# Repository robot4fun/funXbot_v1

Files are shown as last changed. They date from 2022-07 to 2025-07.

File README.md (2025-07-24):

<p align="center">
  <picture>
    <source media="(prefers-color-scheme: dark)" srcset="doc/funxedu-logo4-white.png">
    <source media="(prefers-color-scheme: light)" srcset="doc/funxedu-logo4-black.png">
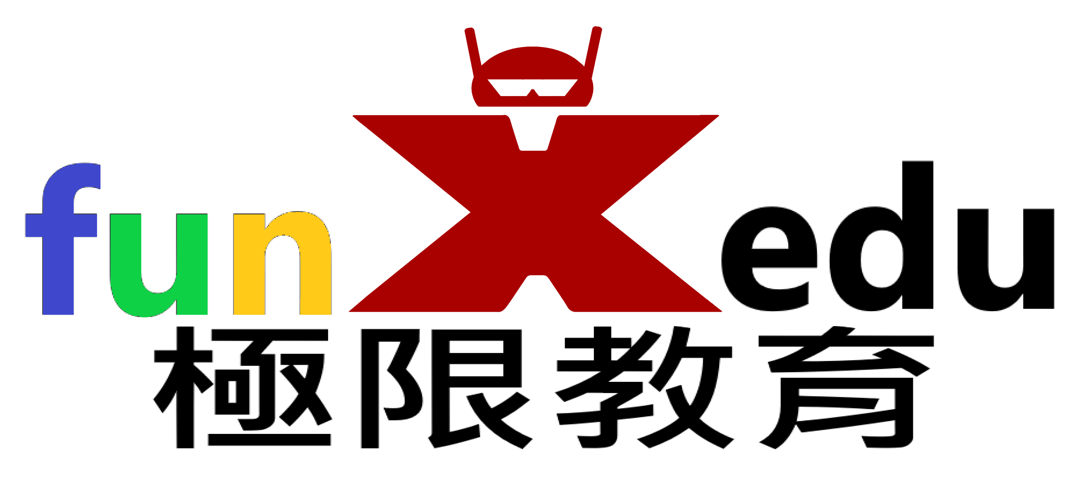
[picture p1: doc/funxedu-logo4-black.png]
funXedu
    
  </picture>
  <br/>
</p>

`funXbot v1` 是一個低成本、DIY（自己動手做）的機器人套件項目，專為教育用途設計。

!! 此專案授權僅限個人或學校教學非商業用途。嚴禁任何商業使用、分發或用於商業目的之修改 !!

# 項目包含三大部分
* `funXbot`: 主機、電池盒、感應器、顯示設備和馬達等設備，搭配樂高規格相容積木所組成的完整教育機器人套件
* `funXtcp`: 使用 `KittenBot` (基於 `esp-link` 技術) 韌體的 WiFi 模組，讓 `funXbot v1` 具備無線功能
* `funXblock`: 基於 `Kittenblock` 積木編程軟體 (基於 `Scratch`，但增加了上傳程式讓機器人離線自主動作的功能)，是 `funXbot v1` 的程式開發環境(IDE)，目前僅有 Windows 版

# funXbot v1 套件可以怎麼玩?
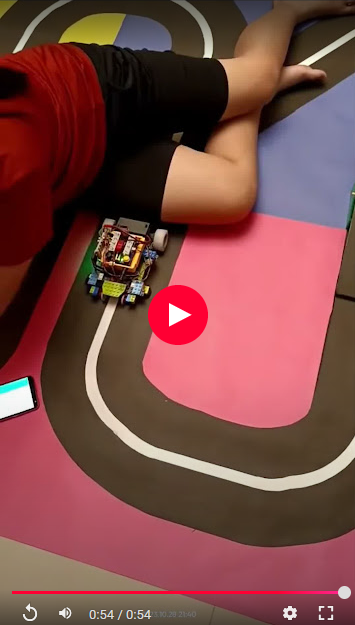
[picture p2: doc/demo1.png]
(https://photos.app.goo.gl/XpYc3omgsmDtc2Y2A)

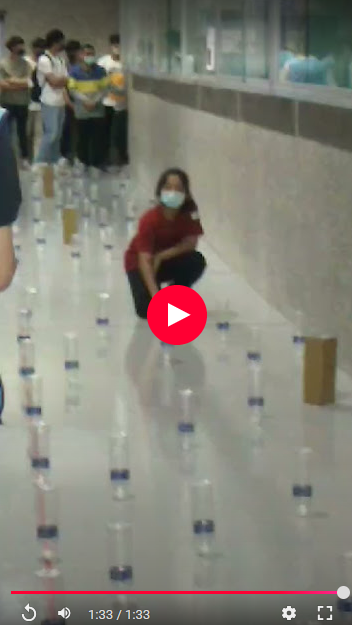
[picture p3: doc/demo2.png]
(https://photos.app.goo.gl/KkY9mZn8f1qZUgqs6)


# DIY 材料清單
* 主機:
    * 32-pin TQFP 封裝的 Arduino UNO R3 開發板
    * MPU6050 加速度計和陀螺儀模組 (I2C接口)
    * 凱斯電子 KSB030 S4A 擴充板
    * Arduino UNO 樂高積木外殼 或 一般外殼

* 電池盒: 可裝2顆14500鋰電池串聯(8.4V)，需附開關，插頭為圓頭 DC 5.5x2.1mm

* funXtcp WiFi模組:
  * ESP12S 模組
  * 洞洞板 + 排針
  * 10KΩ 以上 + 2倍阻值 電阻

* 感應器:
    * 數位感應器模組，例如：紅外線避障、按鈕等
    * 類比感應器模組，例如：紅外線測距
    * HC-SR04 超聲波距離感應器模組
    * DHT11 溫濕度感應器模組
    * TCS34725 RGB顏色感應器模組 (I2C接口)
    * PCF8574T IO擴展模組 (I2C接口)
    * CD74HC4067 類比IO擴展模組
    * QTR-8A 循線模組
    * QMC5883L 磁力計 (I2C接口)
    * 碼盤計數模組

* 顯示設備:
  * TM1637 數字顯示模組
  * MAX7219 8x8 LED顯示模組
  * WS2812B 5050 RGB LED燈條或燈環

* 馬達:
  * SG90 或 MG90 伺服馬達
  * SG90 或 MG90 360度連續旋轉馬達(當一般馬達用)
  * MX1508 直流馬達驅動板
  * USB MicroB 或 TypeC 公 及 母 PCB板
  * TT 直流有刷馬達 或 樂高馬達

* 線材:  
  * 匹配UNO開發板 USB 接口型式的 USB `數據線`
  * RJ11 `6P4C` 和 `6P6C` 水晶頭
  * 電話 或 網路線 (剝皮取線)
  * 杜邦線
  * 熱縮套管

* 樂高規格積木

## 所需工具
* `3D列印機`: 用於製作樂高相容外殼
* `焊接工具`: 用於電路接線
* `RJ11壓接鉗`: 用於連接水晶頭和線材
* `熱風槍`: 熱縮套管用
* `燒錄器`: 用於燒錄程式到 ESP12S 模組中
* `熱熔膠槍`: 用於固定電路板和絕緣
* `PVC膠水`: 用於黏接積木和外殼
* `Windows電腦`: 用於安裝 `funXblock`
* `14500鋰電池充電器`

# funXbot v1 製作方法
## `主機`
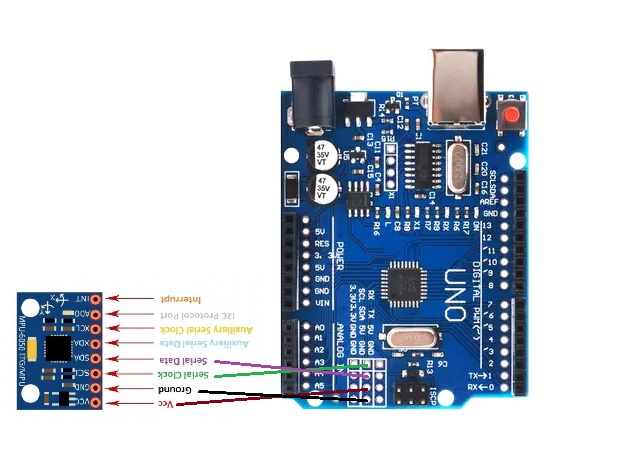
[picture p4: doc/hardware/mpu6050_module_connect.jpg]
  1. 依圖連接 MPU6050 模組和 UNO 開發板後，將 MPU6050 模組依圖示方向 ( x軸朝向左, y軸朝向後, z軸朝上 ) 固定於開發板上 

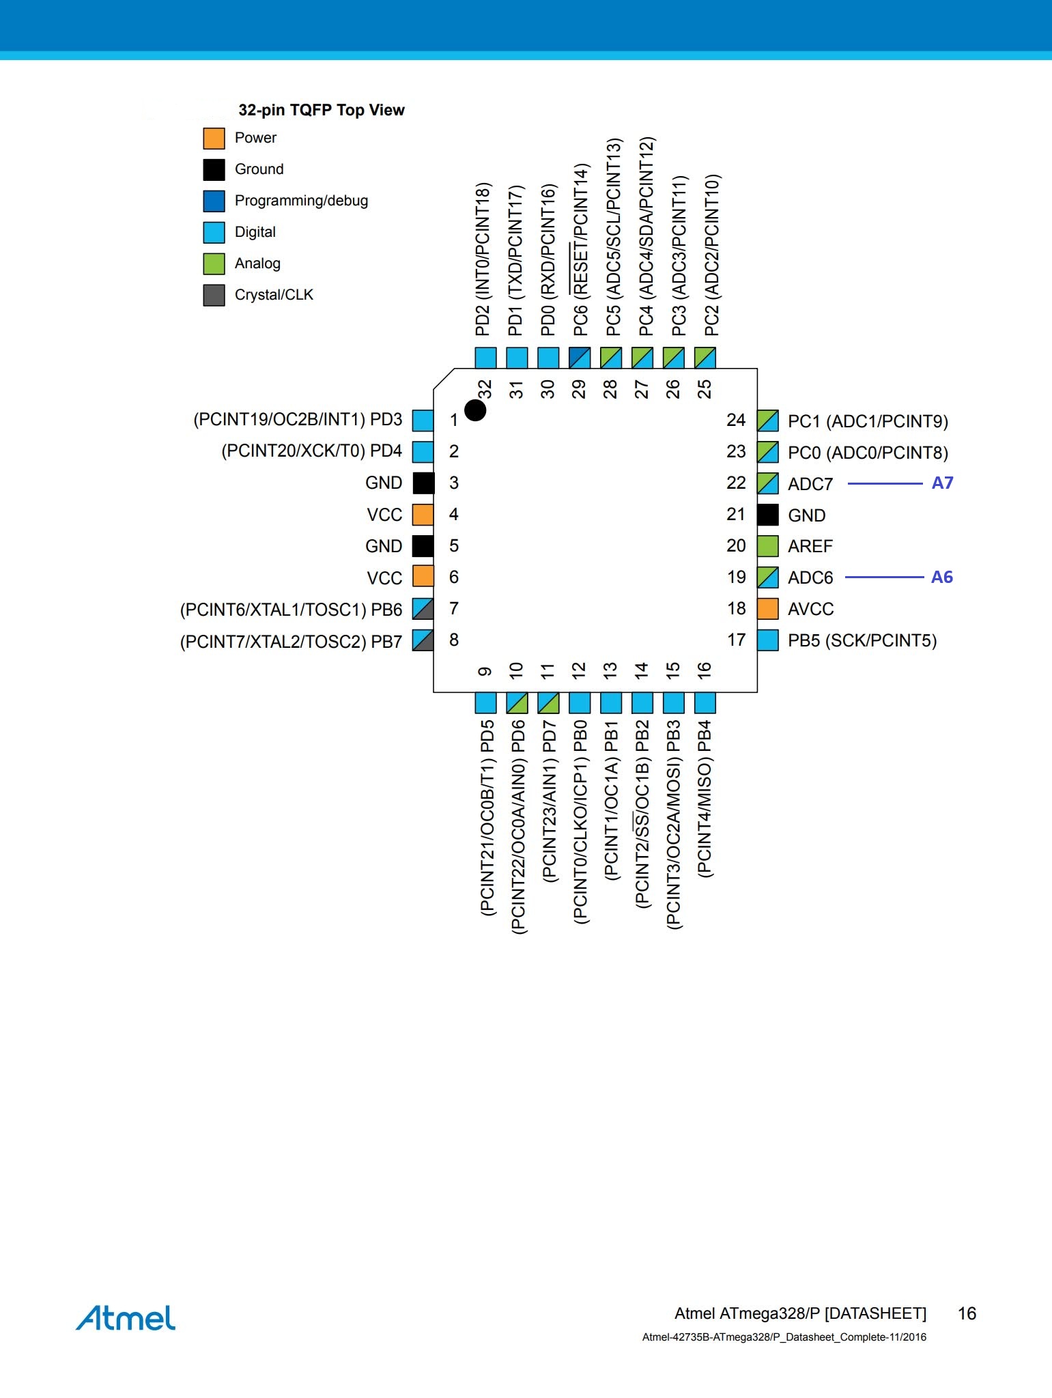
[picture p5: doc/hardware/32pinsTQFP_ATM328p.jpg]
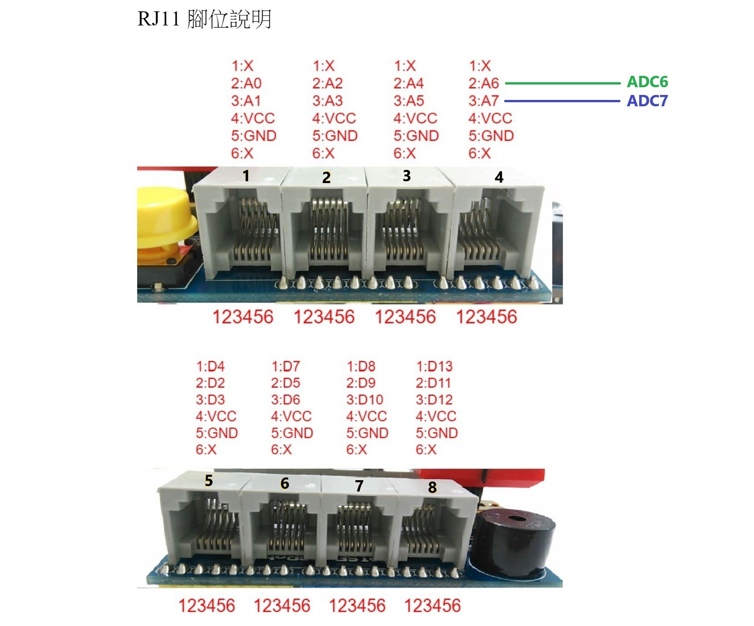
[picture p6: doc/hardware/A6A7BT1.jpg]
  2. 將32-pin TQFP封裝的 ATmega328/P ADC6, ADC7 接到 擴充板的RJ11 A6, A7  

  3. 依照片將擴充板的RJ11接口寫上編號，方便之後連接線材
  
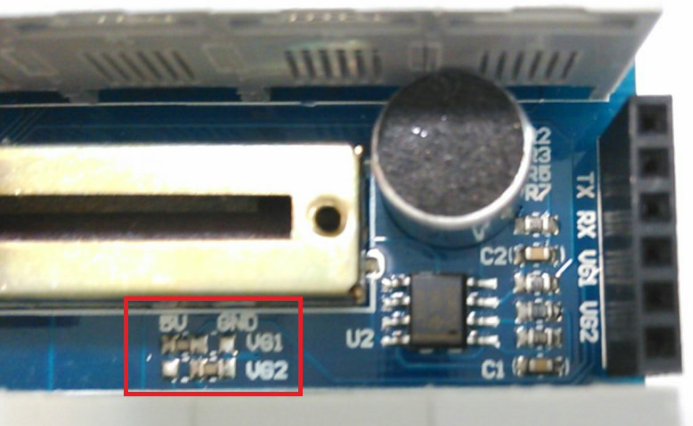
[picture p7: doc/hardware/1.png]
  4. 將擴充板的無線通訊接口(BT1) VG1相對應的電阻移除 

  5. 將擴充板的無線通訊接口(BT1)的VG1腳位接3.3V (funXtcp WiFi模組用)

  6. 將無線通訊接口(BT1) pin6(VG2旁空腳位) 做記號後接 UNO板 RESET 腳位

  7. 將擴充板插入UNO插座後放入Arduino UNO 樂高積木外殼 或 一般外殼中

  8. 如果採用一般外殼，需要在外殼周圍和底部用PVC膠黏接積木，確保積木不會掉落

## `電池盒`
底部用PVC膠黏接積木，確保積木不會掉落

## `funXtcp` WiFi模組
  * 下載 [`wifi/`](/wifi) 目錄內所有韌體檔案 ( *.bin ) 到電腦

  * 將ESP12S模組正確放在 `燒錄器` 上 (如果使用 `USB to TTL` 或 `開發板` 當燒錄器，請確保接線和電壓正確)
  
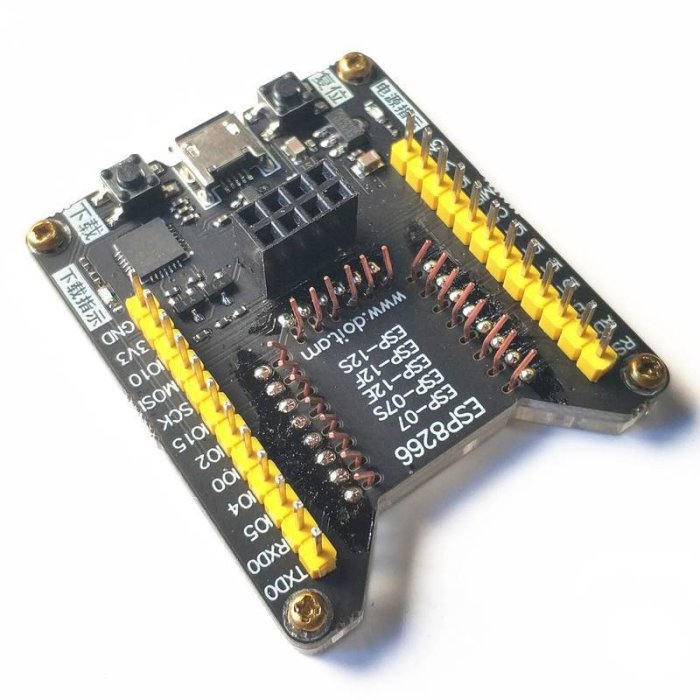
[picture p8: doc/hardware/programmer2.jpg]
  
  
  * 以 `USB 訊號線` (不是充電線) 連接 `電腦` 和 `燒錄器` 

  * 點選進入 [`燒錄工具網頁版`](https://espressif.github.io/esptool-js/)

  * 點選網頁 `Connect` 按鈕，選擇正確的`USB端口` 後點選 `連線`
  
  * `Flash Address` 設為 `0x0` ，點選 `選擇檔案` 按鈕後選擇之前下載的韌體檔 [boot_v1.7.bin](wifi/boot_v1.7.bin)

  * 點選 `Add File` 按鈕後會增加一列，依下表依序增加韌體檔

    | Flash Address | File |
    | :-----------: | :-----: |
    | 0x0000 | [boot_v1.7.bin](wifi/boot_v1.7.bin) |
    | 0x1000 | [user1.bin](wifi/user1.bin) |
    | 0x3FC000 | [esp_init_data_default_v08.bin](wifi/esp_init_data_default_v08.bin) |
    | 0x3FE000 | [blank.bin](wifi/blank.bin) |
  
  * 點選網頁 `Program` 按鈕後開始燒錄韌體
  * 燒錄完成後點選網頁 `Disconnect` 按鈕

  * 按壓ㄧ下燒錄器的 `復位` 按鈕，讓ESP12S模組重新啟動
  
  * 筆電WiFi連接 ESP12S模組 ( 預設SSID: `ESP_00xx` ) 後
    * 以瀏覽器連192.168.4.1 
    * 進入網頁後選 `Upgrade Firmware` 頁面 
    * 點選 `選擇檔案` 選取 [user2.bin](wifi/user2.bin)之後點選 `Update the firmware`
    * reload網頁後將 `serial LED` 改為 `GPIO2` 
    * 視情況更改 `Reset` 腳位，應該是 `GPIO13` 
    * 更新韌體回 [user1.bin](wifi/user1.bin) 
    * 點選 `Home` 頁面後更改 `Hostname` 為 `funXbot`
    * 點選 `WiFi Soft-AP` 頁面後更改 `SSID` 為 `funXtcp00xx` (以MAC當序號)
    * 更改 `Password` 為 `12345678`

  * 拔除 `USB 數據線` 後取下 `ESP12S模組`
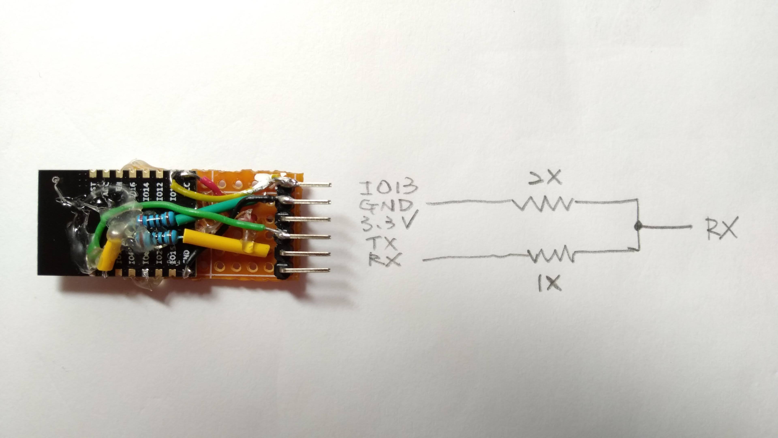
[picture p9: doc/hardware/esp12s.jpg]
  * 依圖自行焊接  之後在 `IO13` 針腳做標記 
  * 用熱縮套管包覆焊接處，確保不會短路

## `其他設備`
* RJ11 `6P4C` 水晶頭會連接母座的 `2-5腳位`，RJ11 `6P6C` 水晶頭會連接母座的 `1-6腳位` 
* 除電源和接地外，請按以下說明接線:
* 1個水晶頭分支接多設備情況下，`腳位1` 設備標記 `C`，`腳位2` 設備標記 `B`，`腳位3` 設備標記 `A`

* `感應器`: 
  * 類比、數位、DHT11溫溼度 等感應器訊號接 `腳位3` 
  * 超音波感應器 `trig` 訊號接 `腳位2`， `echo` 訊號接 `腳位3`
  * I2C類感應器 `SDA` 訊號接 `腳位2`， `SCL` 訊號接 `腳位3`

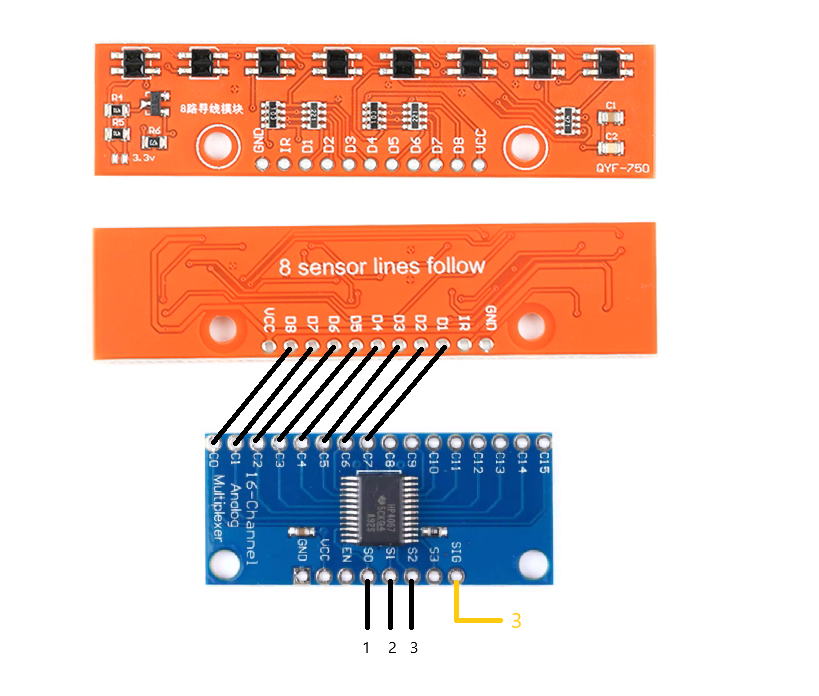
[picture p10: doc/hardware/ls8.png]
* `8路循線感應器`: 由 `QTR-8A 循線模組` 和 `CD74HC4067 類比IO擴展模組` 組成  將兩者的對應腳位連接後，使用 `6P6C` 水晶頭將 CD74HC4067 類比IO擴展模組的 `s0` 接 `腳位1`， `s1` 接 `腳位2`， `s2` 接 `腳位3`， `SIG` 需額外的 `6P4C` 水晶頭，接 `腳位3` 。

* `16路循線感應器`:
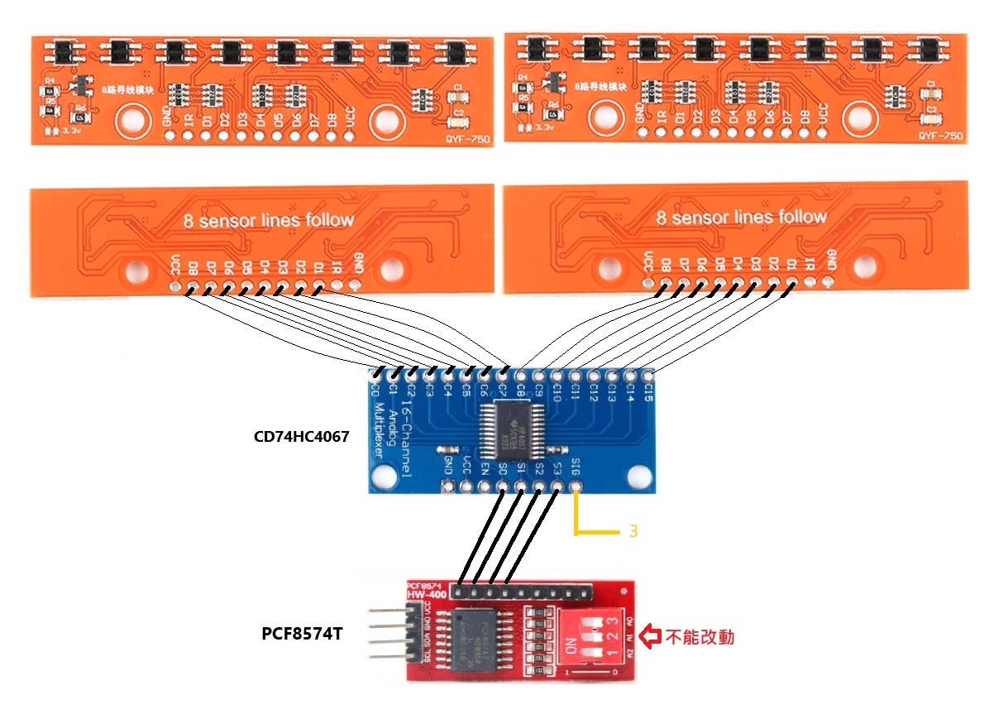
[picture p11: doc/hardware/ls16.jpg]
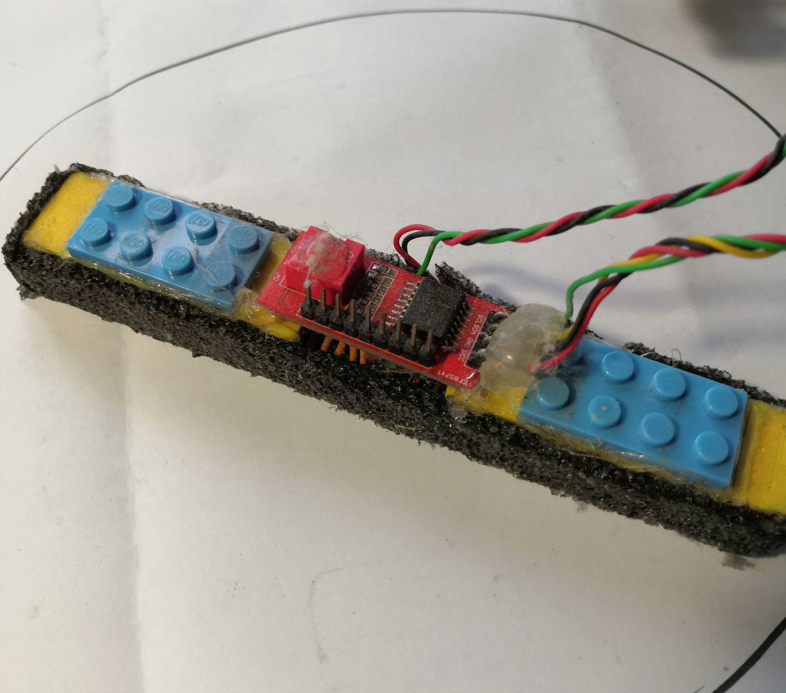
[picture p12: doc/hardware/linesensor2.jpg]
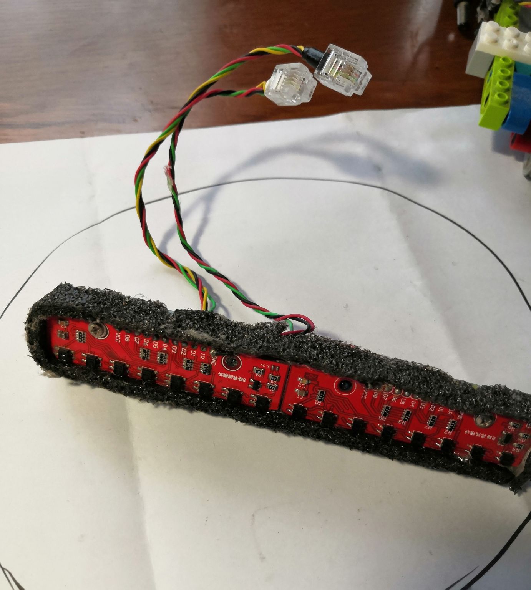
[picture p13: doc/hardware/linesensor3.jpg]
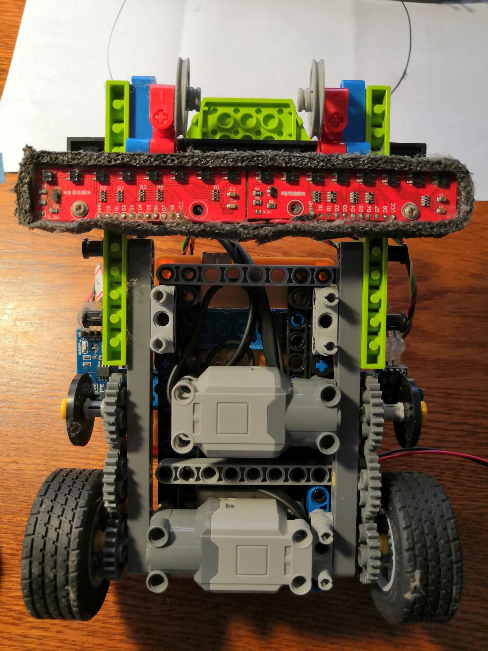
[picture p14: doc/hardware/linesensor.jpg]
  * 2張 `QTR-8A 循線模組` 、 `CD74HC4067 類比IO擴展模組` 和 `PCF8574T IO擴展模組` 組成  依圖將三者的對應腳位連接後，使用 `6P4C` 水晶頭將 PCF8574T 的  `SDA` 訊號接 `腳位2`， `SCL` 訊號接 `腳位3`， CD74HC4067 的 `SIG` 需額外的 `6P4C` 水晶頭，接 `腳位3` 。
  * 如果同時要使用 `顏色感應器` ， 須製作 I2C 轉接頭

* `顯示設備`:
  * TM1637數字顯示板的 `clk` 接 `腳位2` ， `dio` 接 `腳位3`
  * 燈條或燈環訊號接 `腳位3`
  * 將兩個 MAX7219 LED 顯示板拼接後，使用 `6P6C` 水晶頭， `clk` 接 `腳位1` ， `cs` 接 `腳位2` ， `din` 接 `腳位3`

* `馬達`:
  * 伺服馬達接 `腳位3`
  * 360連續旋轉伺服馬達接 `腳位2`  
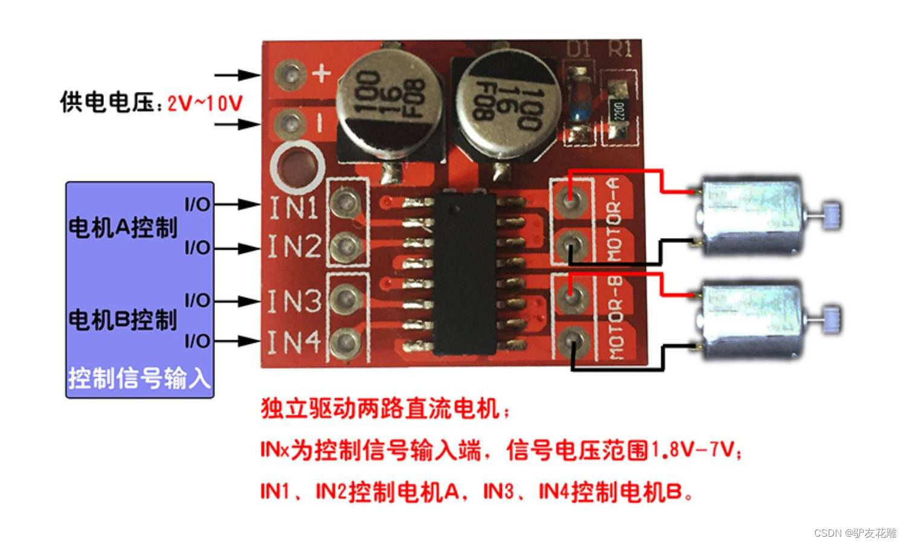
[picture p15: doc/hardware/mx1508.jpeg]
  * 直流馬達需接入 `MX1508 直流馬達驅動板`  1張可驅動2台馬達，因為便宜，每張驅動1台馬達就好。將其黏接在TT馬達上，依圖說接線， `IN1` 接 `腳位2` ， `IN2` 接 `腳位3` 
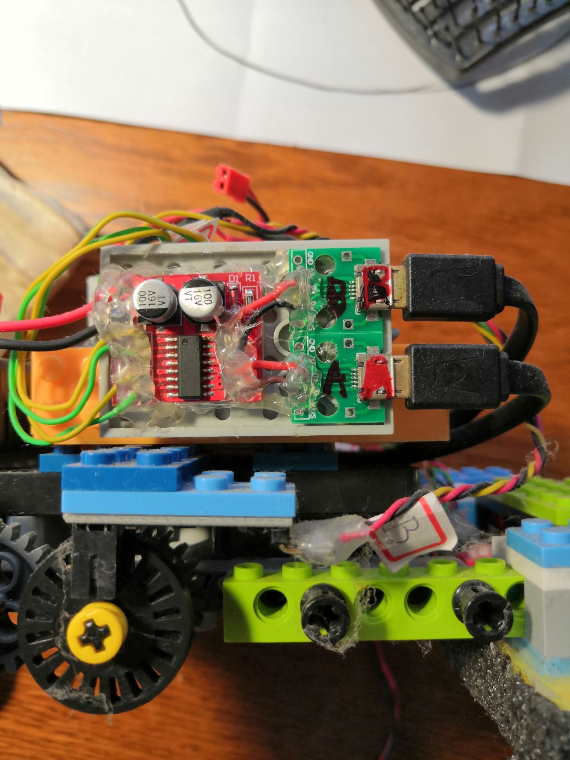
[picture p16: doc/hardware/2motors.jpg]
  * 如果要同時驅動2台直流馬達，須將MX1508驅動板的 `MOTOR` 接 USB `MicroB` 或 `TypeC` 母座，馬達接USB公頭，較為方便
  * 如果要增加馬達功率，可將MX1508驅動板的電源接電池側(可增加電池保護板)，但驅動電流最大也僅2A

* 設備接好線後，可用熱熔膠黏接積木當底座，或3D打印製作外殼( [ `3d/`](3d/) 目錄內有一些設計 )

# `funXblock` 安裝方法
1. 點選下載 [Kittenblock 1.8.4](https://github.com/robot4fun/funXbot_v1/releases/download/v1.0.0/Kittenblock.Setup.1.8.4.exe) 後安裝

2. 點選下載 [`funXblock`](https://github.com/robot4fun/funXbot_v1/archive/refs/tags/v1.0.0.zip) 後解壓縮(或依下圖方式下載)
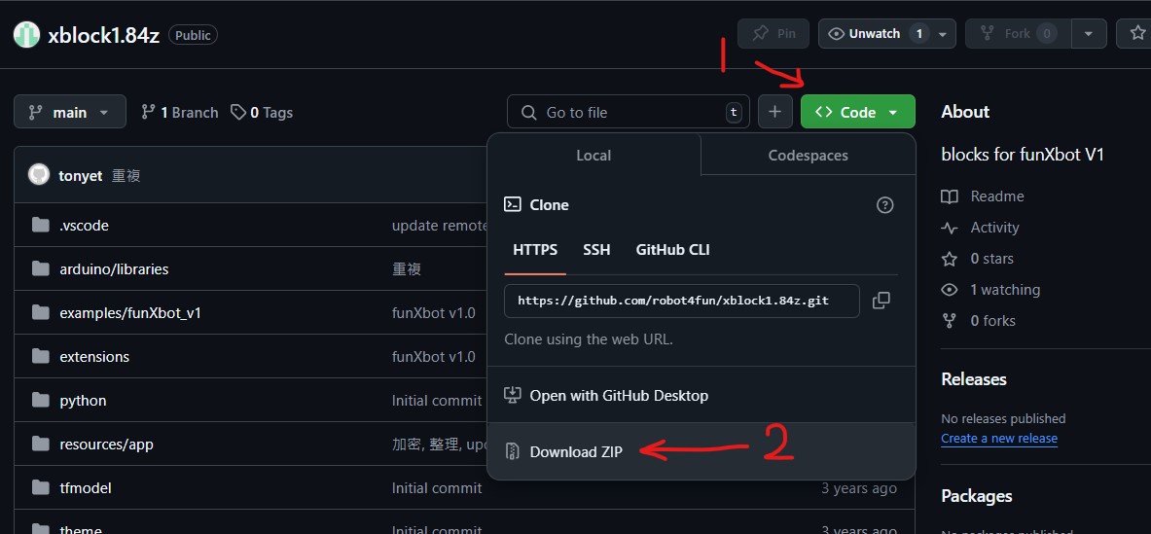
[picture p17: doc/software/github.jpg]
   

4. 以 "管理員權限" 執行 `install.bat`

## 如何在 funXblock 中使用 funXbot v1
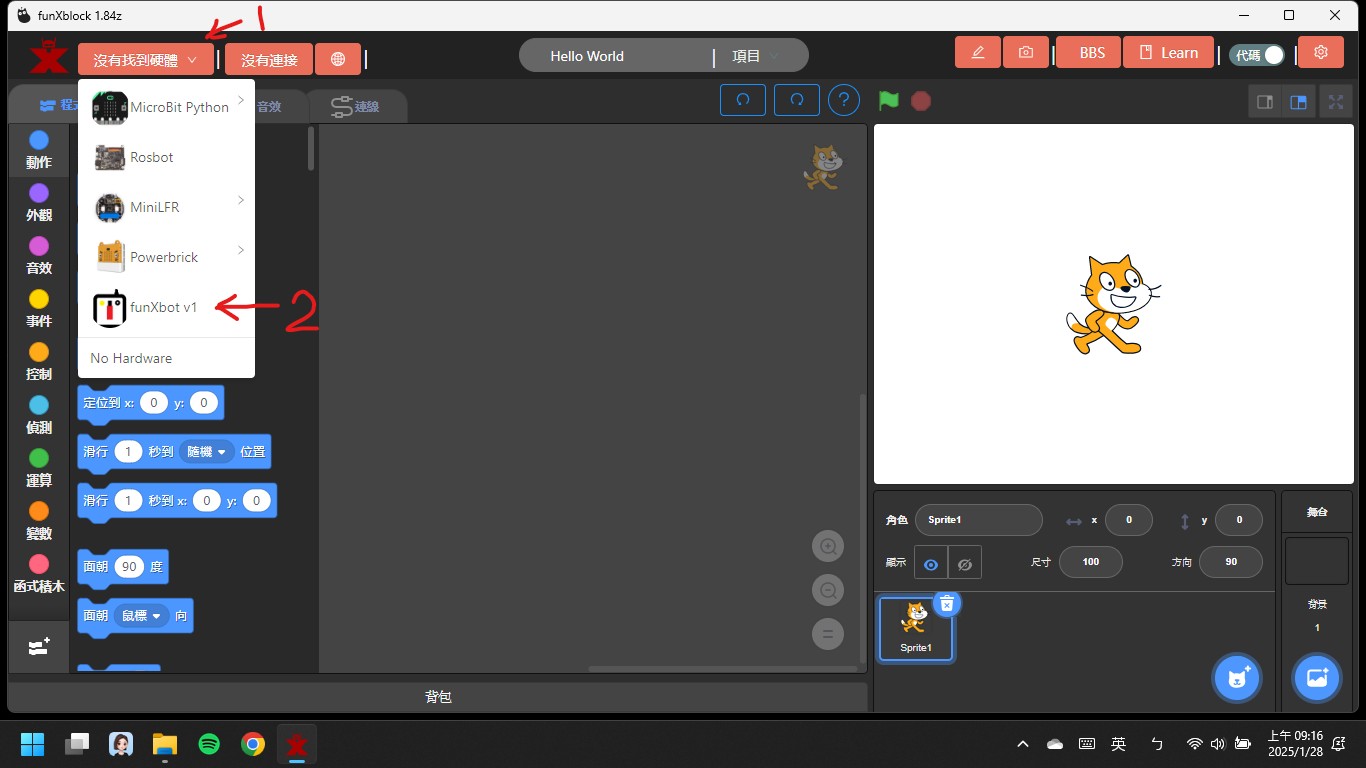
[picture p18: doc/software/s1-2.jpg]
1. 在硬體選單中點選 `funXbot v1`

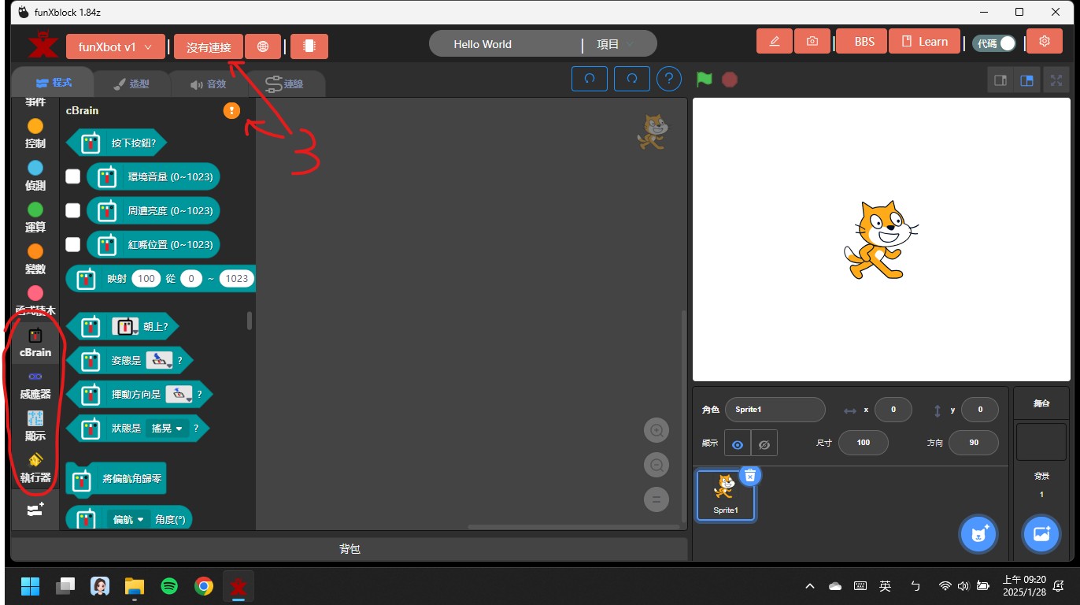
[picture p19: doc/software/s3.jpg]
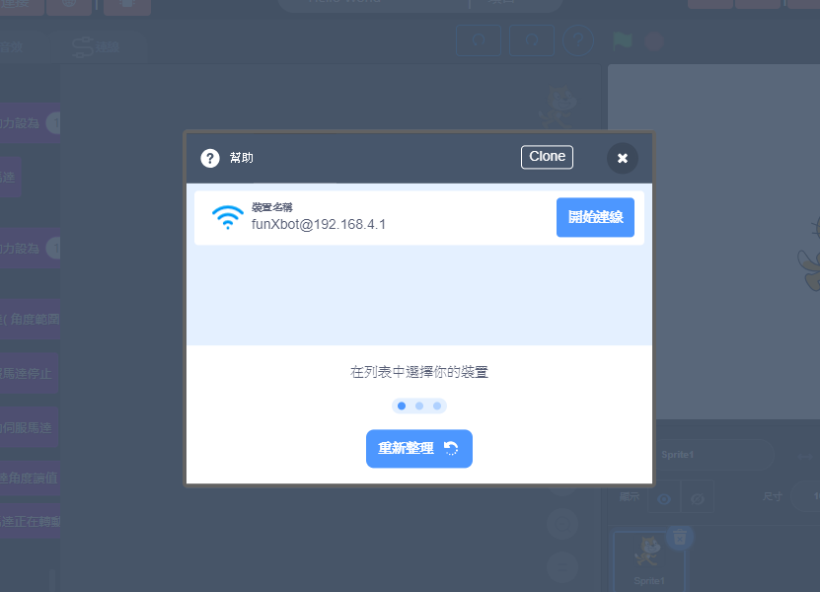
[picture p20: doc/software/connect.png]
2. 點選 `沒有連接` 按鈕或圖示後選擇正確的WiFi或USB埠 `開始連線` funXbot

3. 預設為 `舞台模式` (on-line), 可和電腦連線互動. 如果無法互動, 請點選 `升級韌體`

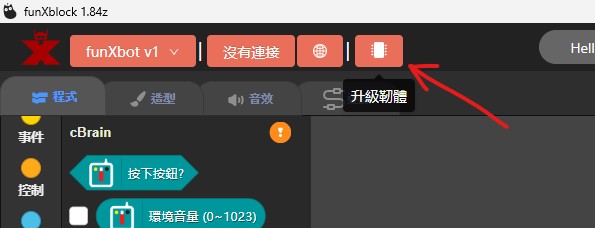
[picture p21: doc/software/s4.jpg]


4. 如果要讓 funXbot 獨立運作, 請點選 `編程模式` (off-line)

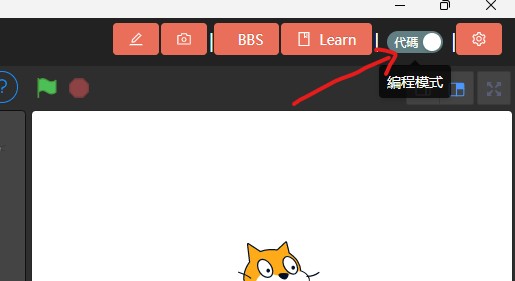
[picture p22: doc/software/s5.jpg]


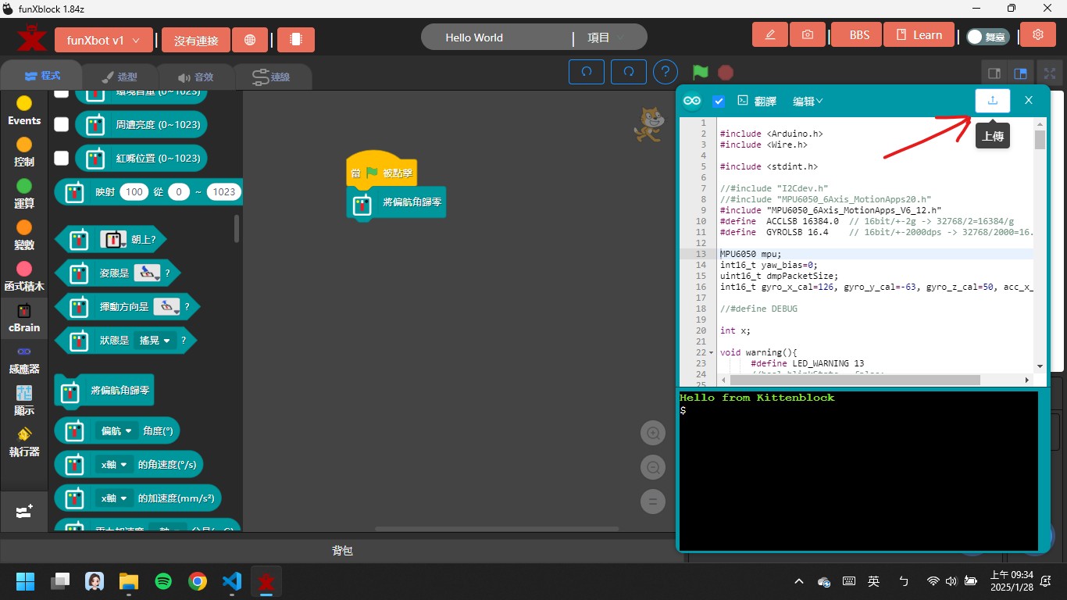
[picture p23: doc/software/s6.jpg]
5. 點選 `編程模式` 後, 會出現C++ 編程視窗, 這裡會自動翻譯積木語言為C++語言. 程式完成後點選 `上傳` 即可上傳到 funXbot 中 

6. 點選 `舞台模式` 即可回到舞台

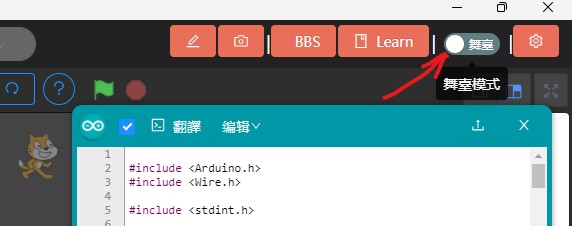
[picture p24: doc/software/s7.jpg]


7. 一旦 `編程模式` (off-line)下曾經上傳過程式, 要再回到 `舞台模式` 和電腦連線互動, 就必須再點選 `升級韌體` 後才可以

# funXbot v1 使用注意事項
1. 接口1A不能和主機內建 光強度感應器 同時使用

2. 接口1B不能和主機內建 滑動式可變電阻(紅嘴) 同時使用

3. 接口2B不能和主機內建 聲強度感應器 同時使用

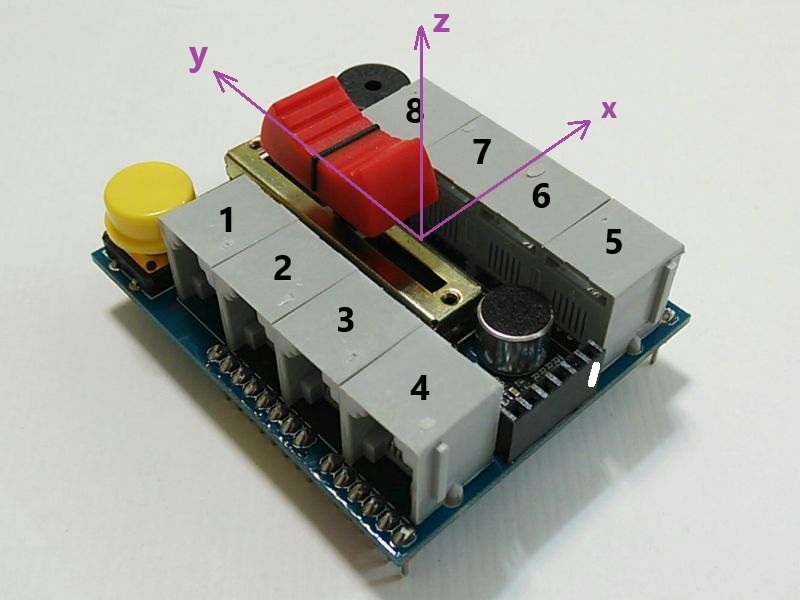
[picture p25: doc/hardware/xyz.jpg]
4. funXblock程式積木所指x軸為朝接口5-8方向; y軸朝向USB及電源接口方向

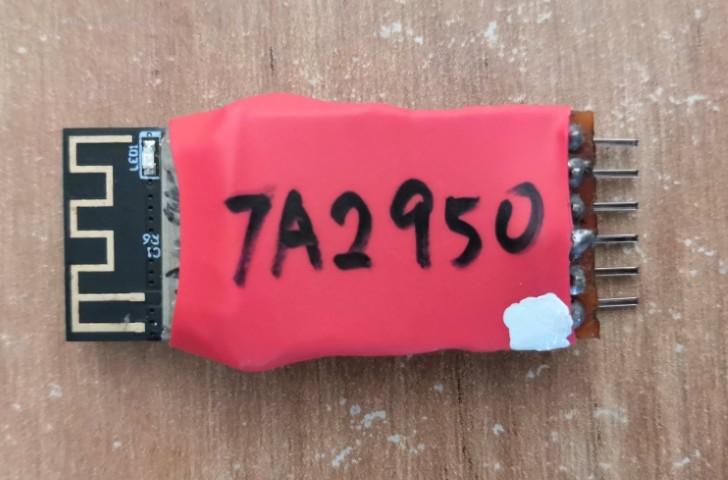
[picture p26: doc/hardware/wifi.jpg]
5. 安插 funXtcp WiFi 模組時, 白色標記需和主控器無線通訊接口白色標記對齊

6. 無線通訊接口無法和有線通訊接口(USB) 同時使用. 使用USB前, 請先拔除funXtcp WiFi 模組

7. 使用無線通訊前, 需先在Windows 連無線網路(SSID: funXtcp00xx, 預設密碼12345678), 再在funXblock中連 funXbot

8. 可使用USB或電池盒供電. 電池盒需要2顆 14500 鋰電池串聯(8.4V), 請勿使用電壓不足的電池, 例如鹼性或鎳氫電池

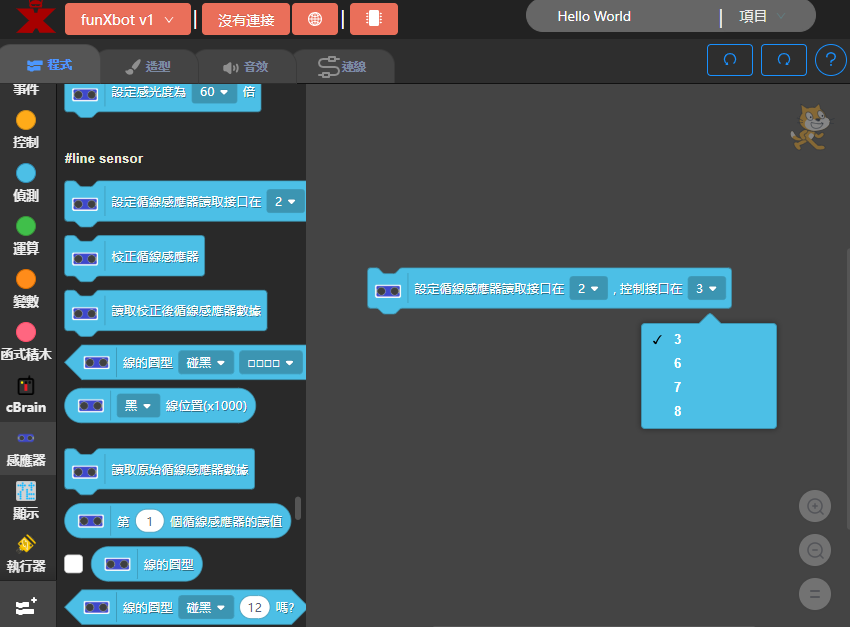
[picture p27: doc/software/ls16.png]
9. `16路循線感應器` `控制接口` 需選 `3`

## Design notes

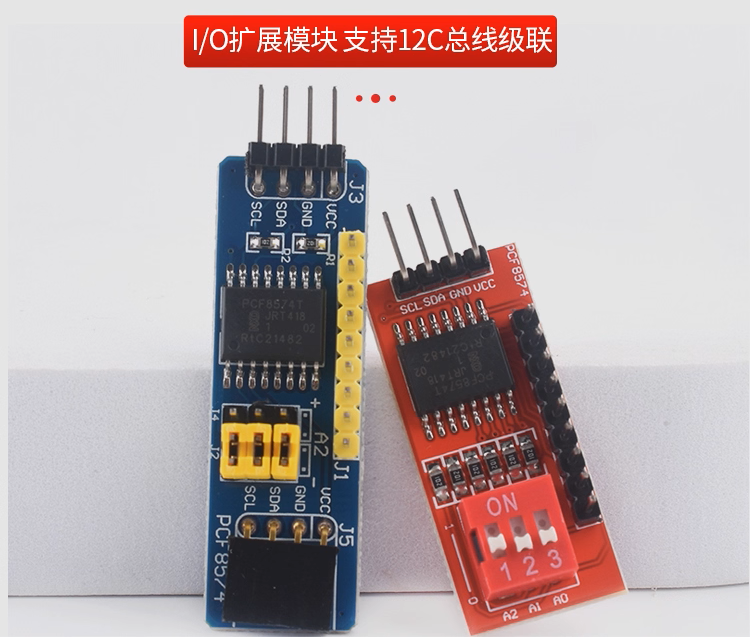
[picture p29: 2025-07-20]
doc/hardware/pcf8574.png

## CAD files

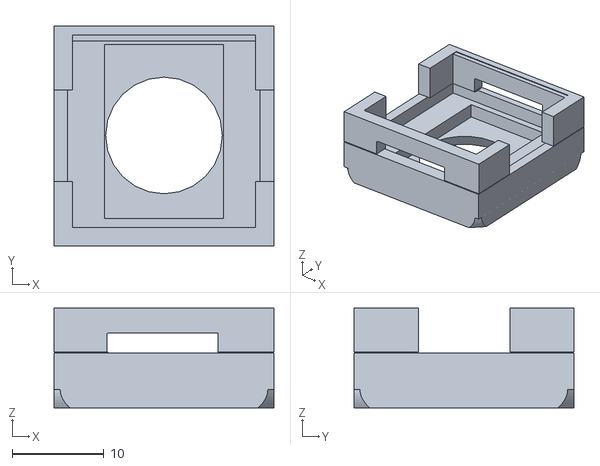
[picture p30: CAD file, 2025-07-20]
3d/color sensor hat v3.stl
24.0 x 24.0 x 10.9

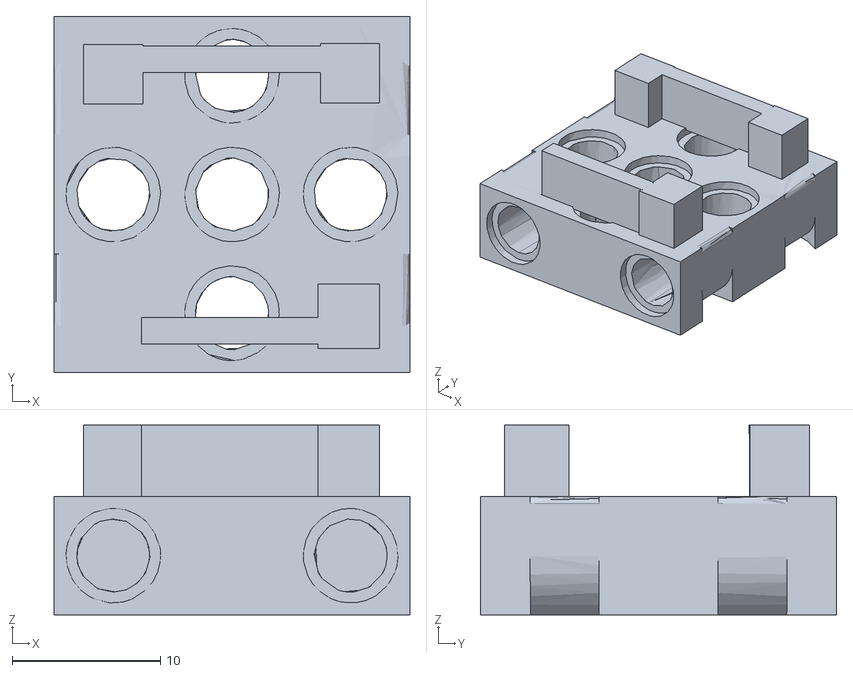
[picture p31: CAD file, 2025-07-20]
3d/color sensor base v4.stl
24.0 x 24.0 x 12.8

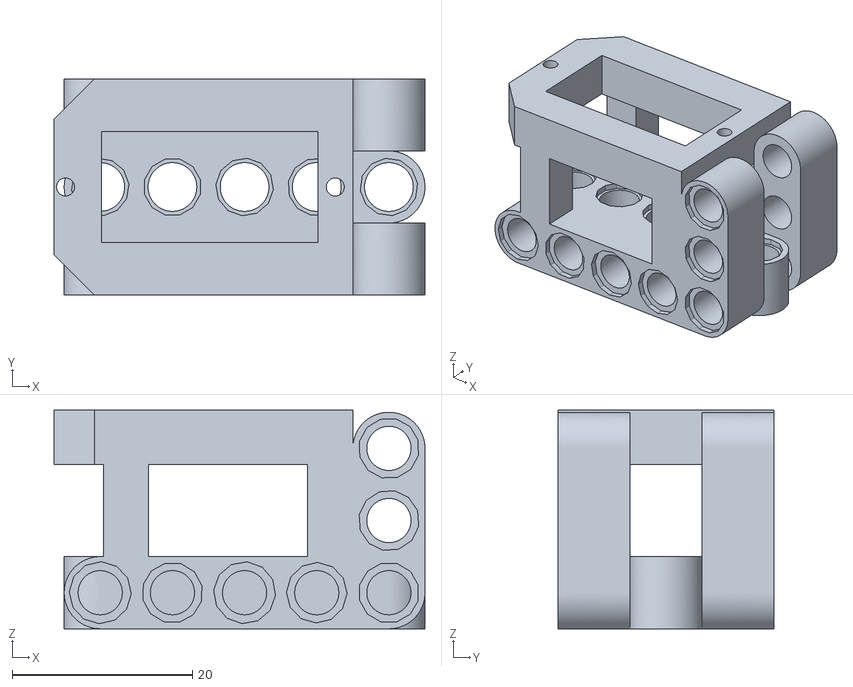
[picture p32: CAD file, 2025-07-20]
3d/servo.stl
41.1 x 24.0 x 24.2

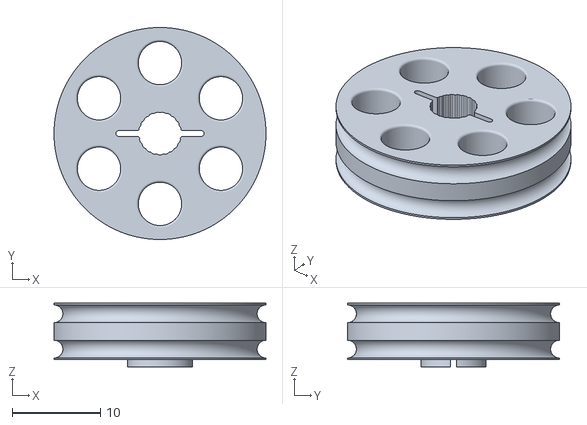
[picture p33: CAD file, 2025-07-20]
3d/9g_servo_fitting_doublepully.STL
24.0 x 24.0 x 7.20

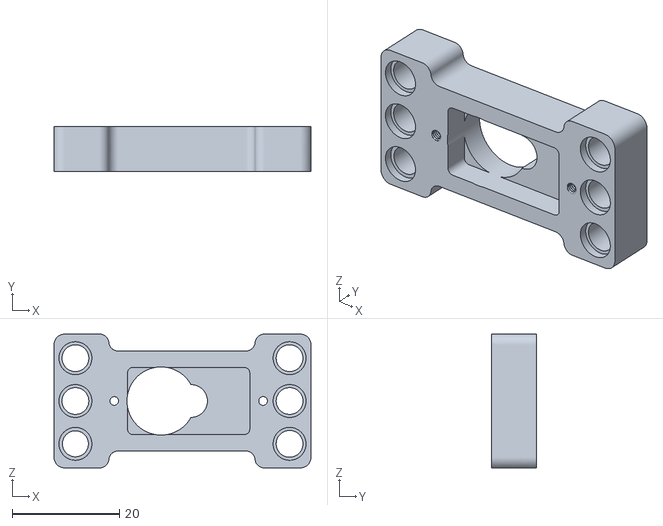
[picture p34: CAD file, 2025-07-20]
3d/SG90_-_Micro_Servo_9g_-_Tower_Pro_v2_LEGO.stl
48.0 x 8.45 x 25.0

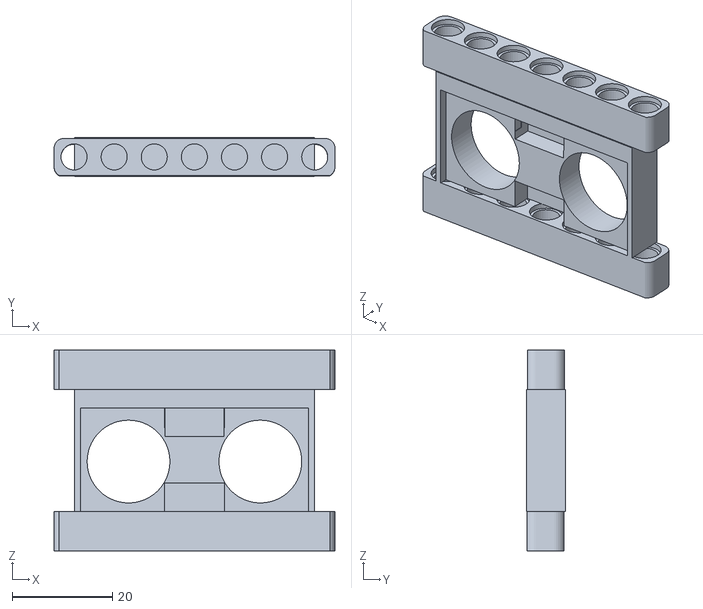
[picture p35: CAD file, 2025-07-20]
3d/HC-SR04 v2.stl
56.0 x 7.80 x 40.1

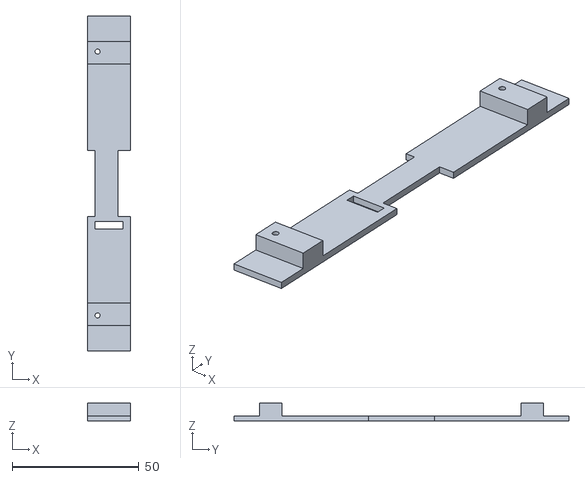
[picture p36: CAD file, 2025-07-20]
3d/line sensor.stl
17.0 x 132.0 x 7.00

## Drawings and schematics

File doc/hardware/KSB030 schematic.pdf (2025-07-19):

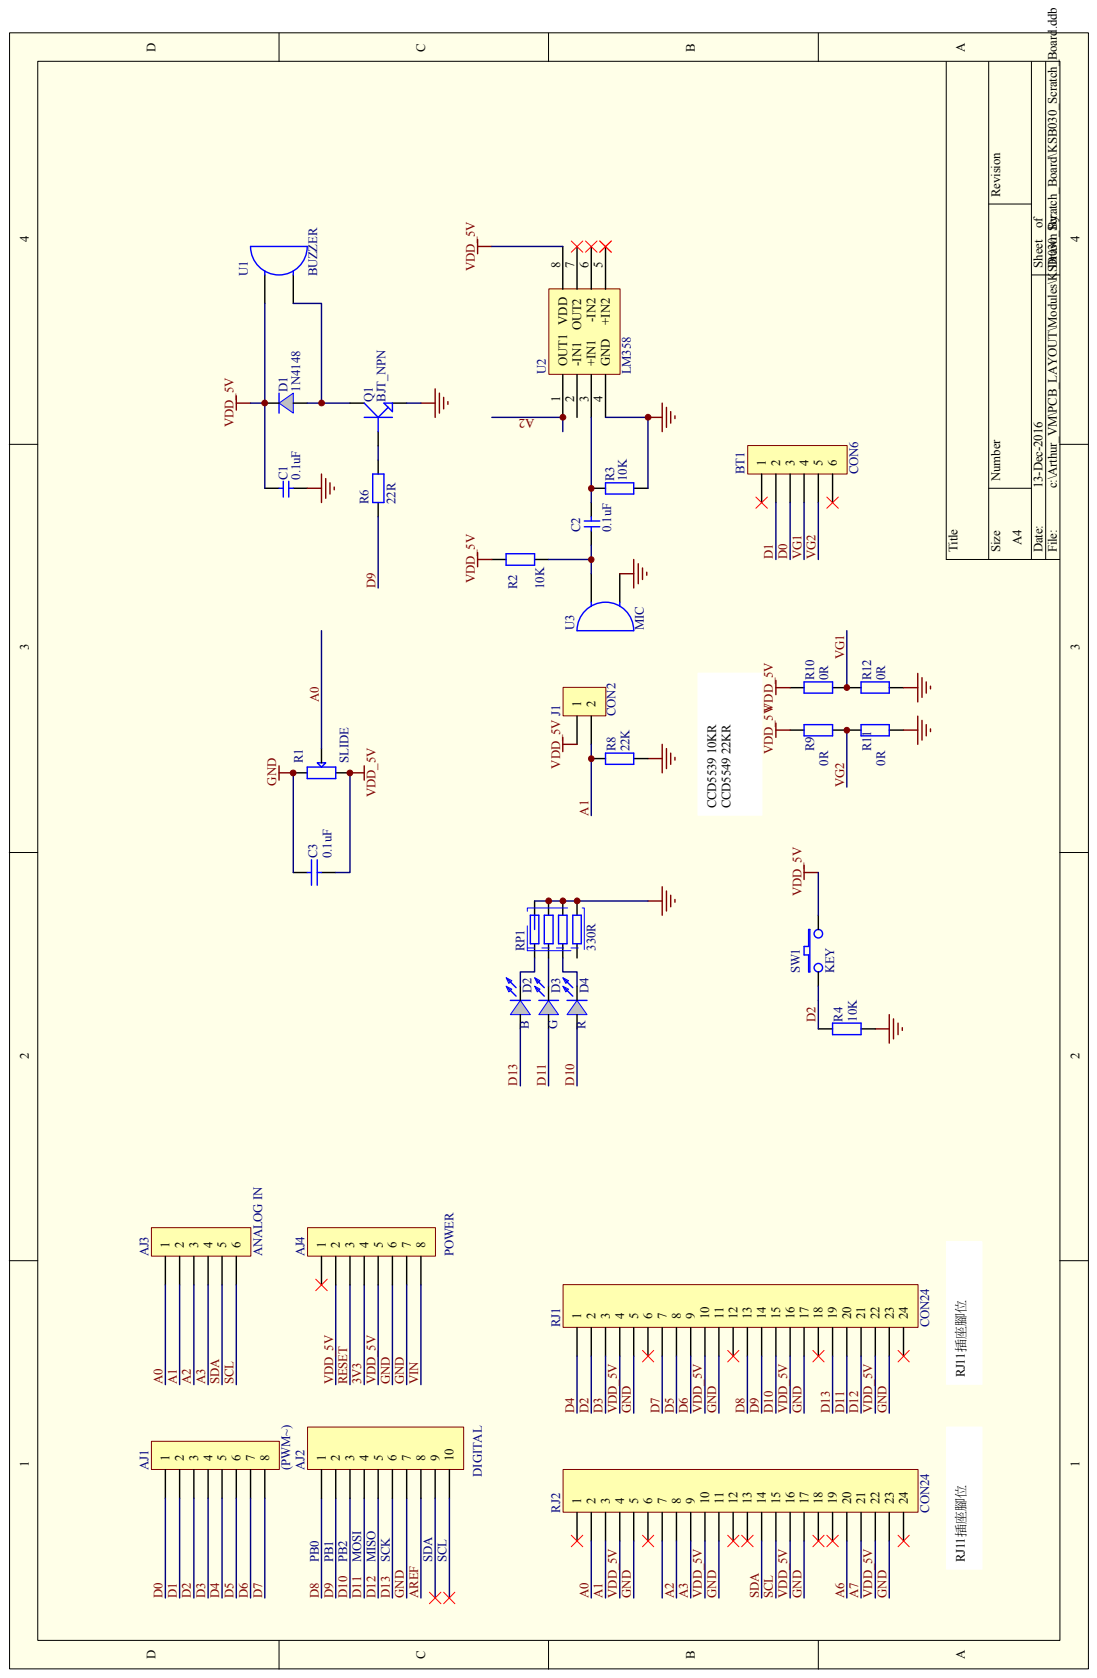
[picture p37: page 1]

File: c:\Arthur_VM\PCB_LAYOUT\Modules\KSB030_Scratch_Board\KSB030_Scratch_Board.ddb Drawn By:

Date: 13-Dec-2016 Sheet of

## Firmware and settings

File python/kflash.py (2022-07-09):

#!/usr/bin/env python3
# -*- coding: utf-8 -*-

from __future__ import (division, print_function)

import sys
import time
import zlib
import copy
import struct
import binascii
import hashlib
import argparse
import math
import zipfile, tempfile
import json
import re
import os

import sys, os
pkgdir = os.path.join(os.getcwd(), 'packages')
sys.path.insert(0, pkgdir)

class KFlash:
    print_callback = None

    def __init__(self, print_callback = None):
        self.killProcess = False
        self.loader = None
        KFlash.print_callback = print_callback

    @staticmethod
    def log(*args, **kwargs):
        if KFlash.print_callback:
            KFlash.print_callback(*args, **kwargs)
        else:
            print(*args, **kwargs)

    def process(self, terminal=True, dev="", baudrate=1500000, board=None, sram = False, file="", callback=None, noansi=False, terminal_auto_size=False, terminal_size=(50, 1), slow_mode = False):
        self.killProcess = False
        BASH_TIPS = dict(NORMAL='\033[0m',BOLD='\033[1m',DIM='\033[2m',UNDERLINE='\033[4m',
                            DEFAULT='\033[0m', RED='\033[31m', YELLOW='\033[33m', GREEN='\033[32m',
                            BG_DEFAULT='\033[49m', BG_WHITE='\033[107m')

        ERROR_MSG   = BASH_TIPS['RED']+BASH_TIPS['BOLD']+'[ERROR]'+BASH_TIPS['NORMAL']
        WARN_MSG    = BASH_TIPS['YELLOW']+BASH_TIPS['BOLD']+'[WARN]'+BASH_TIPS['NORMAL']
        INFO_MSG    = BASH_TIPS['GREEN']+BASH_TIPS['BOLD']+'[INFO]'+BASH_TIPS['NORMAL']

        VID_LIST_FOR_AUTO_LOOKUP = "(1A86)|(0403)|(067B)|(10C4)|(C251)|(0403)"
        #                            WCH    FTDI    PL     CL    DAP   OPENEC
        ISP_RECEIVE_TIMEOUT = 0.5

        MAX_RETRY_TIMES = 10

        ISP_FLASH_SECTOR_SIZE = 4096
        ISP_FLASH_DATA_FRAME_SIZE = ISP_FLASH_SECTOR_SIZE * 16

        def tuple2str(t):
            ret = ""
            for i in t:
                ret += i+" "
            return ret

        def raise_exception(exception):
            if self.loader:
                try:
                    self.loader._port.close()
                except Exception:
                    pass
            raise exception

        try:
            from enum import Enum
        except ImportError:
            err = (ERROR_MSG,'enum34 must be installed, run '+BASH_TIPS['GREEN']+'`' + ('pip', 'pip3')[sys.version_info > (3, 0)] + ' install enum34`',BASH_TIPS['DEFAULT'])
            err = tuple2str(err)
            raise Exception(err)
        try:
            import serial
            import serial.tools.list_ports
        except ImportError:
            err = (ERROR_MSG,'PySerial must be installed, run '+BASH_TIPS['GREEN']+'`' + ('pip', 'pip3')[sys.version_info > (3, 0)] + ' install pyserial`',BASH_TIPS['DEFAULT'])
            err = tuple2str(err)
            raise Exception(err)

        class TimeoutError(Exception): pass

        class ProgramFileFormat(Enum):
            FMT_BINARY = 0
            FMT_ELF = 1
            FMT_KFPKG = 2

        # AES is from: https://github.com/ricmoo/pyaes, Copyright by Richard Moore
        class AES:
            '''Encapsulates the AES block cipher.
            You generally should not need this. Use the AESModeOfOperation classes
            below instead.'''
            @staticmethod
            def _compact_word(word):
                return (word[0] << 24) | (word[1] << 16) | (word[2] << 8) | word[3]

            # Number of rounds by keysize
            number_of_rounds = {16: 10, 24: 12, 32: 14}

            # Round constant words
            rcon = [ 0x01, 0x02, 0x04, 0x08, 0x10, 0x20, 0x40, 0x80, 0x1b, 0x36, 0x6c, 0xd8, 0xab, 0x4d, 0x9a, 0x2f, 0x5e, 0xbc, 0x63, 0xc6, 0x97, 0x35, 0x6a, 0xd4, 0xb3, 0x7d, 0xfa, 0xef, 0xc5, 0x91 ]

            # S-box and Inverse S-box (S is for Substitution)
            S = [ 0x63, 0x7c, 0x77, 0x7b, 0xf2, 0x6b, 0x6f, 0xc5, 0x30, 0x01, 0x67, 0x2b, 0xfe, 0xd7, 0xab, 0x76, 0xca, 0x82, 0xc9, 0x7d, 0xfa, 0x59, 0x47, 0xf0, 0xad, 0xd4, 0xa2, 0xaf, 0x9c, 0xa4, 0x72, 0xc0, 0xb7, 0xfd, 0x93, 0x26, 0x36, 0x3f, 0xf7, 0xcc, 0x34, 0xa5, 0xe5, 0xf1, 0x71, 0xd8, 0x31, 0x15, 0x04, 0xc7, 0x23, 0xc3, 0x18, 0x96, 0x05, 0x9a, 0x07, 0x12, 0x80, 0xe2, 0xeb, 0x27, 0xb2, 0x75, 0x09, 0x83, 0x2c, 0x1a, 0x1b, 0x6e, 0x5a, 0xa0, 0x52, 0x3b, 0xd6, 0xb3, 0x29, 0xe3, 0x2f, 0x84, 0x53, 0xd1, 0x00, 0xed, 0x20, 0xfc, 0xb1, 0x5b, 0x6a, 0xcb, 0xbe, 0x39, 0x4a, 0x4c, 0x58, 0xcf, 0xd0, 0xef, 0xaa, 0xfb, 0x43, 0x4d, 0x33, 0x85, 0x45, 0xf9, 0x02, 0x7f, 0x50, 0x3c, 0x9f, 0xa8, 0x51, 0xa3, 0x40, 0x8f, 0x92, 0x9d, 0x38, 0xf5, 0xbc, 0xb6, 0xda, 0x21, 0x10, 0xff, 0xf3, 0xd2, 0xcd, 0x0c, 0x13, 0xec, 0x5f, 0x97, 0x44, 0x17, 0xc4, 0xa7, 0x7e, 0x3d, 0x64, 0x5d, 0x19, 0x73, 0x60, 0x81, 0x4f, 0xdc, 0x22, 0x2a, 0x90, 0x88, 0x46, 0xee, 0xb8, 0x14, 0xde, 0x5e, 0x0b, 0xdb, 0xe0, 0x32, 0x3a, 0x0a, 0x49, 0x06, 0x24, 0x5c, 0xc2, 0xd3, 0xac, 0x62, 0x91, 0x95, 0xe4, 0x79, 0xe7, 0xc8, 0x37, 0x6d, 0x8d, 0xd5, 0x4e, 0xa9, 0x6c, 0x56, 0xf4, 0xea, 0x65, 0x7a, 0xae, 0x08, 0xba, 0x78, 0x25, 0x2e, 0x1c, 0xa6, 0xb4, 0xc6, 0xe8, 0xdd, 0x74, 0x1f, 0x4b, 0xbd, 0x8b, 0x8a, 0x70, 0x3e, 0xb5, 0x66, 0x48, 0x03, 0xf6, 0x0e, 0x61, 0x35, 0x57, 0xb9, 0x86, 0xc1, 0x1d, 0x9e, 0xe1, 0xf8, 0x98, 0x11, 0x69, 0xd9, 0x8e, 0x94, 0x9b, 0x1e, 0x87, 0xe9, 0xce, 0x55, 0x28, 0xdf, 0x8c, 0xa1, 0x89, 0x0d, 0xbf, 0xe6, 0x42, 0x68, 0x41, 0x99, 0x2d, 0x0f, 0xb0, 0x54, 0xbb, 0x16 ]
            Si =[ 0x52, 0x09, 0x6a, 0xd5, 0x30, 0x36, 0xa5, 0x38, 0xbf, 0x40, 0xa3, 0x9e, 0x81, 0xf3, 0xd7, 0xfb, 0x7c, 0xe3, 0x39, 0x82, 0x9b, 0x2f, 0xff, 0x87, 0x34, 0x8e, 0x43, 0x44, 0xc4, 0xde, 0xe9, 0xcb, 0x54, 0x7b, 0x94, 0x32, 0xa6, 0xc2, 0x23, 0x3d, 0xee, 0x4c, 0x95, 0x0b, 0x42, 0xfa, 0xc3, 0x4e, 0x08, 0x2e, 0xa1, 0x66, 0x28, 0xd9, 0x24, 0xb2, 0x76, 0x5b, 0xa2, 0x49, 0x6d, 0x8b, 0xd1, 0x25, 0x72, 0xf8, 0xf6, 0x64, 0x86, 0x68, 0x98, 0x16, 0xd4, 0xa4, 0x5c, 0xcc, 0x5d, 0x65, 0xb6, 0x92, 0x6c, 0x70, 0x48, 0x50, 0xfd, 0xed, 0xb9, 0xda, 0x5e, 0x15, 0x46, 0x57, 0xa7, 0x8d, 0x9d, 0x84, 0x90, 0xd8, 0xab, 0x00, 0x8c, 0xbc, 0xd3, 0x0a, 0xf7, 0xe4, 0x58, 0x05, 0xb8, 0xb3, 0x45, 0x06, 0xd0, 0x2c, 0x1e, 0x8f, 0xca, 0x3f, 0x0f, 0x02, 0xc1, 0xaf, 0xbd, 0x03, 0x01, 0x13, 0x8a, 0x6b, 0x3a, 0x91, 0x11, 0x41, 0x4f, 0x67, 0xdc, 0xea, 0x97, 0xf2, 0xcf, 0xce, 0xf0, 0xb4, 0xe6, 0x73, 0x96, 0xac, 0x74, 0x22, 0xe7, 0xad, 0x35, 0x85, 0xe2, 0xf9, 0x37, 0xe8, 0x1c, 0x75, 0xdf, 0x6e, 0x47, 0xf1, 0x1a, 0x71, 0x1d, 0x29, 0xc5, 0x89, 0x6f, 0xb7, 0x62, 0x0e, 0xaa, 0x18, 0xbe, 0x1b, 0xfc, 0x56, 0x3e, 0x4b, 0xc6, 0xd2, 0x79, 0x20, 0x9a, 0xdb, 0xc0, 0xfe, 0x78, 0xcd, 0x5a, 0xf4, 0x1f, 0xdd, 0xa8, 0x33, 0x88, 0x07, 0xc7, 0x31, 0xb1, 0x12, 0x10, 0x59, 0x27, 0x80, 0xec, 0x5f, 0x60, 0x51, 0x7f, 0xa9, 0x19, 0xb5, 0x4a, 0x0d, 0x2d, 0xe5, 0x7a, 0x9f, 0x93, 0xc9, 0x9c, 0xef, 0xa0, 0xe0, 0x3b, 0x4d, 0xae, 0x2a, 0xf5, 0xb0, 0xc8, 0xeb, 0xbb, 0x3c, 0x83, 0x53, 0x99, 0x61, 0x17, 0x2b, 0x04, 0x7e, 0xba, 0x77, 0xd6, 0x26, 0xe1, 0x69, 0x14, 0x63, 0x55, 0x21, 0x0c, 0x7d ]

            # Transformations for encryption
            T1 = [ 0xc66363a5, 0xf87c7c84, 0xee777799, 0xf67b7b8d, 0xfff2f20d, 0xd66b6bbd, 0xde6f6fb1, 0x91c5c554, 0x60303050, 0x02010103, 0xce6767a9, 0x562b2b7d, 0xe7fefe19, 0xb5d7d762, 0x4dababe6, 0xec76769a, 0x8fcaca45, 0x1f82829d, 0x89c9c940, 0xfa7d7d87, 0xeffafa15, 0xb25959eb, 0x8e4747c9, 0xfbf0f00b, 0x41adadec, 0xb3d4d467, 0x5fa2a2fd, 0x45afafea, 0x239c9cbf, 0x53a4a4f7, 0xe4727296, 0x9bc0c05b, 0x75b7b7c2, 0xe1fdfd1c, 0x3d9393ae, 0x4c26266a, 0x6c36365a, 0x7e3f3f41, 0xf5f7f702, 0x83cccc4f, 0x6834345c, 0x51a5a5f4, 0xd1e5e534, 0xf9f1f108, 0xe2717193, 0xabd8d873, 0x62313153, 0x2a15153f, 0x0804040c, 0x95c7c752, 0x46232365, 0x9dc3c35e, 0x30181828, 0x379696a1, 0x0a05050f, 0x2f9a9ab5, 0x0e070709, 0x24121236, 0x1b80809b, 0xdfe2e23d, 0xcdebeb26, 0x4e272769, 0x7fb2b2cd, 0xea75759f, 0x1209091b, 0x1d83839e, 0x582c2c74, 0x341a1a2e, 0x361b1b2d, 0xdc6e6eb2, 0xb45a5aee, 0x5ba0a0fb, 0xa45252f6, 0x763b3b4d, 0xb7d6d661, 0x7db3b3ce, 0x5229297b, 0xdde3e33e, 0x5e2f2f71, 0x13848497, 0xa65353f5, 0xb9d1d168, 0x00000000, 0xc1eded2c, 0x40202060, 0xe3fcfc1f, 0x79b1b1c8, 0xb65b5bed, 0xd46a6abe, 0x8dcbcb46, 0x67bebed9, 0x7239394b, 0x944a4ade, 0x984c4cd4, 0xb05858e8, 0x85cfcf4a, 0xbbd0d06b, 0xc5efef2a, 0x4faaaae5, 0xedfbfb16, 0x864343c5, 0x9a4d4dd7, 0x66333355, 0x11858594, 0x8a4545cf, 0xe9f9f910, 0x04020206, 0xfe7f7f81, 0xa05050f0, 0x783c3c44, 0x259f9fba, 0x4ba8a8e3, 0xa25151f3, 0x5da3a3fe, 0x804040c0, 0x058f8f8a, 0x3f9292ad, 0x219d9dbc, 0x70383848, 0xf1f5f504, 0x63bcbcdf, 0x77b6b6c1, 0xafdada75, 0x42212163, 0x20101030, 0xe5ffff1a, 0xfdf3f30e, 0xbfd2d26d, 0x81cdcd4c, 0x180c0c14, 0x26131335, 0xc3ecec2f, 0xbe5f5fe1, 0x359797a2, 0x884444cc, 0x2e171739, 0x93c4c457, 0x55a7a7f2, 0xfc7e7e82, 0x7a3d3d47, 0xc86464ac, 0xba5d5de7, 0x3219192b, 0xe6737395, 0xc06060a0, 0x19818198, 0x9e4f4fd1, 0xa3dcdc7f, 0x44222266, 0x542a2a7e, 0x3b9090ab, 0x0b888883, 0x8c4646ca, 0xc7eeee29, 0x6bb8b8d3, 0x2814143c, 0xa7dede79, 0xbc5e5ee2, 0x160b0b1d, 0xaddbdb76, 0xdbe0e03b, 0x64323256, 0x743a3a4e, 0x140a0a1e, 0x924949db, 0x0c06060a, 0x4824246c, 0xb85c5ce4, 0x9fc2c25d, 0xbdd3d36e, 0x43acacef, 0xc46262a6, 0x399191a8, 0x319595a4, 0xd3e4e437, 0xf279798b, 0xd5e7e732, 0x8bc8c843, 0x6e373759, 0xda6d6db7, 0x018d8d8c, 0xb1d5d564, 0x9c4e4ed2, 0x49a9a9e0, 0xd86c6cb4, 0xac5656fa, 0xf3f4f407, 0xcfeaea25, 0xca6565af, 0xf47a7a8e, 0x47aeaee9, 0x10080818, 0x6fbabad5, 0xf0787888, 0x4a25256f, 0x5c2e2e72, 0x381c1c24, 0x57a6a6f1, 0x73b4b4c7, 0x97c6c651, 0xcbe8e823, 0xa1dddd7c, 0xe874749c, 0x3e1f1f21, 0x964b4bdd, 0x61bdbddc, 0x0d8b8b86, 0x0f8a8a85, 0xe0707090, 0x7c3e3e42, 0x71b5b5c4, 0xcc6666aa, 0x904848d8, 0x06030305, 0xf7f6f601, 0x1c0e0e12, 0xc26161a3, 0x6a35355f, 0xae5757f9, 0x69b9b9d0, 0x17868691, 0x99c1c158, 0x3a1d1d27, 0x279e9eb9, 0xd9e1e138, 0xebf8f813, 0x2b9898b3, 0x22111133, 0xd26969bb, 0xa9d9d970, 0x078e8e89, 0x339494a7, 0x2d9b9bb6, 0x3c1e1e22, 0x15878792, 0xc9e9e920, 0x87cece49, 0xaa5555ff, 0x50282878, 0xa5dfdf7a, 0x038c8c8f, 0x59a1a1f8, 0x09898980, 0x1a0d0d17, 0x65bfbfda, 0xd7e6e631, 0x844242c6, 0xd06868b8, 0x824141c3, 0x299999b0, 0x5a2d2d77, 0x1e0f0f11, 0x7bb0b0cb, 0xa85454fc, 0x6dbbbbd6, 0x2c16163a ]
            T2 = [ 0xa5c66363, 0x84f87c7c, 0x99ee7777, 0x8df67b7b, 0x0dfff2f2, 0xbdd66b6b, 0xb1de6f6f, 0x5491c5c5, 0x50603030, 0x03020101, 0xa9ce6767, 0x7d562b2b, 0x19e7fefe, 0x62b5d7d7, 0xe64dabab, 0x9aec7676, 0x458fcaca, 0x9d1f8282, 0x4089c9c9, 0x87fa7d7d, 0x15effafa, 0xebb25959, 0xc98e4747, 0x0bfbf0f0, 0xec41adad, 0x67b3d4d4, 0xfd5fa2a2, 0xea45afaf, 0xbf239c9c, 0xf753a4a4, 0x96e47272, 0x5b9bc0c0, 0xc275b7b7, 0x1ce1fdfd, 0xae3d9393, 0x6a4c2626, 0x5a6c3636, 0x417e3f3f, 0x02f5f7f7, 0x4f83cccc, 0x5c683434, 0xf451a5a5, 0x34d1e5e5, 0x08f9f1f1, 0x93e27171, 0x73abd8d8, 0x53623131, 0x3f2a1515, 0x0c080404, 0x5295c7c7, 0x65462323, 0x5e9dc3c3, 0x28301818, 0xa1379696, 0x0f0a0505, 0xb52f9a9a, 0x090e0707, 0x36241212, 0x9b1b8080, 0x3ddfe2e2, 0x26cdebeb, 0x694e2727, 0xcd7fb2b2, 0x9fea7575, 0x1b120909, 0x9e1d8383, 0x74582c2c, 0x2e341a1a, 0x2d361b1b, 0xb2dc6e6e, 0xeeb45a5a, 0xfb5ba0a0, 0xf6a45252, 0x4d763b3b, 0x61b7d6d6, 0xce7db3b3, 0x7b522929, 0x3edde3e3, 0x715e2f2f, 0x97138484, 0xf5a65353, 0x68b9d1d1, 0x00000000, 0x2cc1eded, 0x60402020, 0x1fe3fcfc, 0xc879b1b1, 0xedb65b5b, 0xbed46a6a, 0x468dcbcb, 0xd967bebe, 0x4b723939, 0xde944a4a, 0xd4984c4c, 0xe8b05858, 0x4a85cfcf, 0x6bbbd0d0, 0x2ac5efef, 0xe54faaaa, 0x16edfbfb, 0xc5864343, 0xd79a4d4d, 0x55663333, 0x94118585, 0xcf8a4545, 0x10e9f9f9, 0x06040202, 0x81fe7f7f, 0xf0a05050, 0x44783c3c, 0xba259f9f, 0xe34ba8a8, 0xf3a25151, 0xfe5da3a3, 0xc0804040, 0x8a058f8f, 0xad3f9292, 0xbc219d9d, 0x48703838, 0x04f1f5f5, 0xdf63bcbc, 0xc177b6b6, 0x75afdada, 0x63422121, 0x30201010, 0x1ae5ffff, 0x0efdf3f3, 0x6dbfd2d2, 0x4c81cdcd, 0x14180c0c, 0x35261313, 0x2fc3ecec, 0xe1be5f5f, 0xa2359797, 0xcc884444, 0x392e1717, 0x5793c4c4, 0xf255a7a7, 0x82fc7e7e, 0x477a3d3d, 0xacc86464, 0xe7ba5d5d, 0x2b321919, 0x95e67373, 0xa0c06060, 0x98198181, 0xd19e4f4f, 0x7fa3dcdc, 0x66442222, 0x7e542a2a, 0xab3b9090, 0x830b8888, 0xca8c4646, 0x29c7eeee, 0xd36bb8b8, 0x3c281414, 0x79a7dede, 0xe2bc5e5e, 0x1d160b0b, 0x76addbdb, 0x3bdbe0e0, 0x56643232, 0x4e743a3a, 0x1e140a0a, 0xdb924949, 0x0a0c0606, 0x6c482424, 0xe4b85c5c, 0x5d9fc2c2, 0x6ebdd3d3, 0xef43acac, 0xa6c46262, 0xa8399191, 0xa4319595, 0x37d3e4e4, 0x8bf27979, 0x32d5e7e7, 0x438bc8c8, 0x596e3737, 0xb7da6d6d, 0x8c018d8d, 0x64b1d5d5, 0xd29c4e4e, 0xe049a9a9, 0xb4d86c6c, 0xfaac5656, 0x07f3f4f4, 0x25cfeaea, 0xafca6565, 0x8ef47a7a, 0xe947aeae, 0x18100808, 0xd56fbaba, 0x88f07878, 0x6f4a2525, 0x725c2e2e, 0x24381c1c, 0xf157a6a6, 0xc773b4b4, 0x5197c6c6, 0x23cbe8e8, 0x7ca1dddd, 0x9ce87474, 0x213e1f1f, 0xdd964b4b, 0xdc61bdbd, 0x860d8b8b, 0x850f8a8a, 0x90e07070, 0x427c3e3e, 0xc471b5b5, 0xaacc6666, 0xd8904848, 0x05060303, 0x01f7f6f6, 0x121c0e0e, 0xa3c26161, 0x5f6a3535, 0xf9ae5757, 0xd069b9b9, 0x91178686, 0x5899c1c1, 0x273a1d1d, 0xb9279e9e, 0x38d9e1e1, 0x13ebf8f8, 0xb32b9898, 0x33221111, 0xbbd26969, 0x70a9d9d9, 0x89078e8e, 0xa7339494, 0xb62d9b9b, 0x223c1e1e, 0x92158787, 0x20c9e9e9, 0x4987cece, 0xffaa5555, 0x78502828, 0x7aa5dfdf, 0x8f038c8c, 0xf859a1a1, 0x80098989, 0x171a0d0d, 0xda65bfbf, 0x31d7e6e6, 0xc6844242, 0xb8d06868, 0xc3824141, 0xb0299999, 0x775a2d2d, 0x111e0f0f, 0xcb7bb0b0, 0xfca85454, 0xd66dbbbb, 0x3a2c1616 ]
            T3 = [ 0x63a5c663, 0x7c84f87c, 0x7799ee77, 0x7b8df67b, 0xf20dfff2, 0x6bbdd66b, 0x6fb1de6f, 0xc55491c5, 0x30506030, 0x01030201, 0x67a9ce67, 0x2b7d562b, 0xfe19e7fe, 0xd762b5d7, 0xabe64dab, 0x769aec76, 0xca458fca, 0x829d1f82, 0xc94089c9, 0x7d87fa7d, 0xfa15effa, 0x59ebb259, 0x47c98e47, 0xf00bfbf0, 0xadec41ad, 0xd467b3d4, 0xa2fd5fa2, 0xafea45af, 0x9cbf239c, 0xa4f753a4, 0x7296e472, 0xc05b9bc0, 0xb7c275b7, 0xfd1ce1fd, 0x93ae3d93, 0x266a4c26, 0x365a6c36, 0x3f417e3f, 0xf702f5f7, 0xcc4f83cc, 0x345c6834, 0xa5f451a5, 0xe534d1e5, 0xf108f9f1, 0x7193e271, 0xd873abd8, 0x31536231, 0x153f2a15, 0x040c0804, 0xc75295c7, 0x23654623, 0xc35e9dc3, 0x18283018, 0x96a13796, 0x050f0a05, 0x9ab52f9a, 0x07090e07, 0x12362412, 0x809b1b80, 0xe23ddfe2, 0xeb26cdeb, 0x27694e27, 0xb2cd7fb2, 0x759fea75, 0x091b1209, 0x839e1d83, 0x2c74582c, 0x1a2e341a, 0x1b2d361b, 0x6eb2dc6e, 0x5aeeb45a, 0xa0fb5ba0, 0x52f6a452, 0x3b4d763b, 0xd661b7d6, 0xb3ce7db3, 0x297b5229, 0xe33edde3, 0x2f715e2f, 0x84971384, 0x53f5a653, 0xd168b9d1, 0x00000000, 0xed2cc1ed, 0x20604020, 0xfc1fe3fc, 0xb1c879b1, 0x5bedb65b, 0x6abed46a, 0xcb468dcb, 0xbed967be, 0x394b7239, 0x4ade944a, 0x4cd4984c, 0x58e8b058, 0xcf4a85cf, 0xd06bbbd0, 0xef2ac5ef, 0xaae54faa, 0xfb16edfb, 0x43c58643, 0x4dd79a4d, 0x33556633, 0x85941185, 0x45cf8a45, 0xf910e9f9, 0x02060402, 0x7f81fe7f, 0x50f0a050, 0x3c44783c, 0x9fba259f, 0xa8e34ba8, 0x51f3a251, 0xa3fe5da3, 0x40c08040, 0x8f8a058f, 0x92ad3f92, 0x9dbc219d, 0x38487038, 0xf504f1f5, 0xbcdf63bc, 0xb6c177b6, 0xda75afda, 0x21634221, 0x10302010, 0xff1ae5ff, 0xf30efdf3, 0xd26dbfd2, 0xcd4c81cd, 0x0c14180c, 0x13352613, 0xec2fc3ec, 0x5fe1be5f, 0x97a23597, 0x44cc8844, 0x17392e17, 0xc45793c4, 0xa7f255a7, 0x7e82fc7e, 0x3d477a3d, 0x64acc864, 0x5de7ba5d, 0x192b3219, 0x7395e673, 0x60a0c060, 0x81981981, 0x4fd19e4f, 0xdc7fa3dc, 0x22664422, 0x2a7e542a, 0x90ab3b90, 0x88830b88, 0x46ca8c46, 0xee29c7ee, 0xb8d36bb8, 0x143c2814, 0xde79a7de, 0x5ee2bc5e, 0x0b1d160b, 0xdb76addb, 0xe03bdbe0, 0x32566432, 0x3a4e743a, 0x0a1e140a, 0x49db9249, 0x060a0c06, 0x246c4824, 0x5ce4b85c, 0xc25d9fc2, 0xd36ebdd3, 0xacef43ac, 0x62a6c462, 0x91a83991, 0x95a43195, 0xe437d3e4, 0x798bf279, 0xe732d5e7, 0xc8438bc8, 0x37596e37, 0x6db7da6d, 0x8d8c018d, 0xd564b1d5, 0x4ed29c4e, 0xa9e049a9, 0x6cb4d86c, 0x56faac56, 0xf407f3f4, 0xea25cfea, 0x65afca65, 0x7a8ef47a, 0xaee947ae, 0x08181008, 0xbad56fba, 0x7888f078, 0x256f4a25, 0x2e725c2e, 0x1c24381c, 0xa6f157a6, 0xb4c773b4, 0xc65197c6, 0xe823cbe8, 0xdd7ca1dd, 0x749ce874, 0x1f213e1f, 0x4bdd964b, 0xbddc61bd, 0x8b860d8b, 0x8a850f8a, 0x7090e070, 0x3e427c3e, 0xb5c471b5, 0x66aacc66, 0x48d89048, 0x03050603, 0xf601f7f6, 0x0e121c0e, 0x61a3c261, 0x355f6a35, 0x57f9ae57, 0xb9d069b9, 0x86911786, 0xc15899c1, 0x1d273a1d, 0x9eb9279e, 0xe138d9e1, 0xf813ebf8, 0x98b32b98, 0x11332211, 0x69bbd269, 0xd970a9d9, 0x8e89078e, 0x94a73394, 0x9bb62d9b, 0x1e223c1e, 0x87921587, 0xe920c9e9, 0xce4987ce, 0x55ffaa55, 0x28785028, 0xdf7aa5df, 0x8c8f038c, 0xa1f859a1, 0x89800989, 0x0d171a0d, 0xbfda65bf, 0xe631d7e6, 0x42c68442, 0x68b8d068, 0x41c38241, 0x99b02999, 0x2d775a2d, 0x0f111e0f, 0xb0cb7bb0, 0x54fca854, 0xbbd66dbb, 0x163a2c16 ]
            T4 = [ 0x6363a5c6, 0x7c7c84f8, 0x777799ee, 0x7b7b8df6, 0xf2f20dff, 0x6b6bbdd6, 0x6f6fb1de, 0xc5c55491, 0x30305060, 0x01010302, 0x6767a9ce, 0x2b2b7d56, 0xfefe19e7, 0xd7d762b5, 0xababe64d, 0x76769aec, 0xcaca458f, 0x82829d1f, 0xc9c94089, 0x7d7d87fa, 0xfafa15ef, 0x5959ebb2, 0x4747c98e, 0xf0f00bfb, 0xadadec41, 0xd4d467b3, 0xa2a2fd5f, 0xafafea45, 0x9c9cbf23, 0xa4a4f753, 0x727296e4, 0xc0c05b9b, 0xb7b7c275, 0xfdfd1ce1, 0x9393ae3d, 0x26266a4c, 0x36365a6c, 0x3f3f417e, 0xf7f702f5, 0xcccc4f83, 0x34345c68, 0xa5a5f451, 0xe5e534d1, 0xf1f108f9, 0x717193e2, 0xd8d873ab, 0x31315362, 0x15153f2a, 0x04040c08, 0xc7c75295, 0x23236546, 0xc3c35e9d, 0x18182830, 0x9696a137, 0x05050f0a, 0x9a9ab52f, 0x0707090e, 0x12123624, 0x80809b1b, 0xe2e23ddf, 0xebeb26cd, 0x2727694e, 0xb2b2cd7f, 0x75759fea, 0x09091b12, 0x83839e1d, 0x2c2c7458, 0x1a1a2e34, 0x1b1b2d36, 0x6e6eb2dc, 0x5a5aeeb4, 0xa0a0fb5b, 0x5252f6a4, 0x3b3b4d76, 0xd6d661b7, 0xb3b3ce7d, 0x29297b52, 0xe3e33edd, 0x2f2f715e, 0x84849713, 0x5353f5a6, 0xd1d168b9, 0x00000000, 0xeded2cc1, 0x20206040, 0xfcfc1fe3, 0xb1b1c879, 0x5b5bedb6, 0x6a6abed4, 0xcbcb468d, 0xbebed967, 0x39394b72, 0x4a4ade94, 0x4c4cd498, 0x5858e8b0, 0xcfcf4a85, 0xd0d06bbb, 0xefef2ac5, 0xaaaae54f, 0xfbfb16ed, 0x4343c586, 0x4d4dd79a, 0x33335566, 0x85859411, 0x4545cf8a, 0xf9f910e9, 0x02020604, 0x7f7f81fe, 0x5050f0a0, 0x3c3c4478, 0x9f9fba25, 0xa8a8e34b, 0x5151f3a2, 0xa3a3fe5d, 0x4040c080, 0x8f8f8a05, 0x9292ad3f, 0x9d9dbc21, 0x38384870, 0xf5f504f1, 0xbcbcdf63, 0xb6b6c177, 0xdada75af, 0x21216342, 0x10103020, 0xffff1ae5, 0xf3f30efd, 0xd2d26dbf, 0xcdcd4c81, 0x0c0c1418, 0x13133526, 0xecec2fc3, 0x5f5fe1be, 0x9797a235, 0x4444cc88, 0x1717392e, 0xc4c45793, 0xa7a7f255, 0x7e7e82fc, 0x3d3d477a, 0x6464acc8, 0x5d5de7ba, 0x19192b32, 0x737395e6, 0x6060a0c0, 0x81819819, 0x4f4fd19e, 0xdcdc7fa3, 0x22226644, 0x2a2a7e54, 0x9090ab3b, 0x8888830b, 0x4646ca8c, 0xeeee29c7, 0xb8b8d36b, 0x14143c28, 0xdede79a7, 0x5e5ee2bc, 0x0b0b1d16, 0xdbdb76ad, 0xe0e03bdb, 0x32325664, 0x3a3a4e74, 0x0a0a1e14, 0x4949db92, 0x06060a0c, 0x24246c48, 0x5c5ce4b8, 0xc2c25d9f, 0xd3d36ebd, 0xacacef43, 0x6262a6c4, 0x9191a839, 0x9595a431, 0xe4e437d3, 0x79798bf2, 0xe7e732d5, 0xc8c8438b, 0x3737596e, 0x6d6db7da, 0x8d8d8c01, 0xd5d564b1, 0x4e4ed29c, 0xa9a9e049, 0x6c6cb4d8, 0x5656faac, 0xf4f407f3, 0xeaea25cf, 0x6565afca, 0x7a7a8ef4, 0xaeaee947, 0x08081810, 0xbabad56f, 0x787888f0, 0x25256f4a, 0x2e2e725c, 0x1c1c2438, 0xa6a6f157, 0xb4b4c773, 0xc6c65197, 0xe8e823cb, 0xdddd7ca1, 0x74749ce8, 0x1f1f213e, 0x4b4bdd96, 0xbdbddc61, 0x8b8b860d, 0x8a8a850f, 0x707090e0, 0x3e3e427c, 0xb5b5c471, 0x6666aacc, 0x4848d890, 0x03030506, 0xf6f601f7, 0x0e0e121c, 0x6161a3c2, 0x35355f6a, 0x5757f9ae, 0xb9b9d069, 0x86869117, 0xc1c15899, 0x1d1d273a, 0x9e9eb927, 0xe1e138d9, 0xf8f813eb, 0x9898b32b, 0x11113322, 0x6969bbd2, 0xd9d970a9, 0x8e8e8907, 0x9494a733, 0x9b9bb62d, 0x1e1e223c, 0x87879215, 0xe9e920c9, 0xcece4987, 0x5555ffaa, 0x28287850, 0xdfdf7aa5, 0x8c8c8f03, 0xa1a1f859, 0x89898009, 0x0d0d171a, 0xbfbfda65, 0xe6e631d7, 0x4242c684, 0x6868b8d0, 0x4141c382, 0x9999b029, 0x2d2d775a, 0x0f0f111e, 0xb0b0cb7b, 0x5454fca8, 0xbbbbd66d, 0x16163a2c ]
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

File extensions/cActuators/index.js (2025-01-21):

var _0x154299=_0x2303;function _0x3845(){var _0x498289=['23300664ZhSVyx','split','replace','\x5cw+','3011996hevBdF','7209351aqqewx','|||board|PIN|||||255||ArgumentType|PORT|type||defaultValue|servo_||SPEED|pin2firmata|_port|STRING|menu|||const|text||MAX|||valueToCode|motor|BlockType|this|blockType||||func|servo|return|opcode|at|port|arguments|gen|arduino|parseInt|2500|VarSpeedServo|let|COMMAND|DEG|1500|definitions_|to||speed|noop|544|includes_||include|map|dPort|dPin|MODES|five|Fn|continuousServo|servoGo|angle|sPort|getServoDeg|value|constrain|setupCodes_|attach|500|motorH|motorHstop|180|maxAngle|Scratch|formatMessage|menuIconURI|the|range|total|isMoving|mode|pins|pinMode|analogWrite|blockIconURI|id|Set|power|pwmPort2|SLIDER|Stop|continuousServoGen|servoGoGen|servoWait|stop|servoWaitGen|servoStop|servoStopGen|getServoDegGen|isMovingGen|McontinuousServo|MservoGo|360|MservoWait|MservoStop|MgetServoDeg|MisMoving|SERVO|if|log|cActuatorsExtension|Actuator|bd10e0|big|100|motorHGen|motorHstopGen|small|dPort3|Servo|rotate|NUMBER|SLIDERANALOGWR|Waitting|for|REPORTER|reading|BOOLEAN|is|moving|zh|Promise|reject|servoConfig|line|ORDER_ATOMIC|sp2pulse|else|PWM|mx1508|funXbot_MX1508|mx1508_|funXbotMX1508|SLOW_DECAY|PWM_2PIN|OUTPUT|digitalWrite|LOW|data|image|png|base64|iVBORw0KGgoAAAANSUhEUgAAADIAAAAyCAYAAAAeP4ixAAAAAXNSR0IArs4c6QAACu1JREFUaEPNmXtYVHUax7|c4a5yFUYYETkIpaBihBeMxMLk|dRvORWbj49am2u2pqXrOy22a6W9Wxa6dPF3dbseTbbrYSUzEstWHmtbATFEIuRCBkYcJDb3M757fM7OMOcuTEgtv3|48z7u3zO|37f9|0dCH4DIycnJ8Th6NwmEvpjuf7cy305EunLpL7McRzBDELIBgokAfiCt9IlZCrMALjM0SO2A3QBCH20TH|ujb6s|6uAOI5hESjZAiDKeUgKVCpAs0cvTX8NhNwPSteVlZ17rS8QbM51Bxk9OmNpis665fWHf1YP1tpl52zt4I0Fz6bFX2nnVl0LxHUHycxKXwVKXgSgHhRtx87HDdBGOmQwLR2cIZoX0slUWBbl5qrNYcp1EGlR0b5D|qysrCgB9gUcRRKltLisrOIrfx67bh5xh3BuHhPhwK6nqr1gWJh9dDg5|4MjNzDo|QBsVot9el1Dw9MgyHPOJ8Cjp09XbPYFc11AZuQNW|Vzo1LyhOemKfE27HzCgHCNIPupwayxrtw|UWVzcNJzURRhNDXBYrXJ7Aiw7PTpirc81|13EPtR5NvtXOFDW5LV5dUan5HAYLavvujlmV|aBuDJnWPRbglxwVxqNMFmk2uLI|RWvf7sEffF|xXEcQTzQcibLDu1dvJYsjkJlbVeTpH296cZgzFcgnH3jBcMIW|W6c8uvy4gvlKszUGw8KUUvzD|NNPlmXFotyhcZ60zNsDq9AzB82X6ivX9DiIcw1LalZ1cdcK5CYN5aHMyAoWZL814woiUwtjINGPVc0Q5Va||Xs2LqGtccWo6jmAOQHS6IkDjA3iDTRjAwwWiGUopOm236oUNfHuxXsXtCcMkvgehWAJwa4vn5oE3|ce3XV80wz6x9Z4JLMwA6RUJv37v38|P94hGZJjg1uMTnAN1KNJ19EhrtbQiNmwrhWx1Au9NnMJp59zEDPDsAL80QfPnJ3kNTrhlEpgkGkfQiEPdHmMrX4IphO9Qxt2Lw5FKI5eNB277pdZj1oBk9UfBzi4r2G9jCWVkZWZQiv9ca8QqnlC0yCOepU|JrQYyvgNa94lVLrkUzxSdSMx7ecOYcW3RE9ojRvEhLATT3CsQTgiT|GSRhncsT7ieOy3kPYRE6iBVXOwwSAtDuwsY086etQ|xmM1ZnWALwDDOpaxboxMzlNyUSjmMQdRwRC4IGcS92zgPzN|Elto9EojniExbAW3Gegjfp4Mb|jFI|ETQ5t0Qz9|n0k1PCYDVGV|aYTC3r71R1dLOt3JEnKXX|2AICsRfneCGf4R2C4Xx5L1eIFxIFFJnmACHGYLDgubKDdBmvgpauwG09i8u|57CjHnmg2eqvXozg1GJfx6IG|XCWz|fYYv1COLLE85TkPiHgKTNqP40GqDyJpDZJOfXAKINv3x9BxwdF5Ew6QDUfCvEyrt6nQB81RlnmJHJuBwQxKvYeb53RRT4sc2o|oOdJoOe4fX0IfRXl8sQbARm|UGwgcO69aN24y|agaAQXELTfUL4u6JDqsCB04loqouArERFtw1yYDIAV31gc|uQsulgzCdXuEF4vkgZuRLiEqcBeH74T5t|6oZUPp7nyCOY7gHlLzN2g5BJHh9zwh8XaFzbR4VasPmPxxHZKgNXMoWUO1CVH|q7REkInUpYke|AOGkV0vWK8143TQJvdc3yFHCqtgYtnq1MRxr3xnvdcjF085j5tgakKh8cOn7cPFgmiuE|BGFDb4b8WN3QTiukqViT|ueEoDH5czMK2i6P5A6dmVgG3xbpcWLH2Z5na1gXA0W5Z0HSIikE1PFs2j58fWAXlHHTMbgySUQ9DcBnecD2gajmbdX1ZgTY62LFbegyDfIEW4HCF3EdmL6WPHWLTC3K2Ubr19wCqOSm6Vn3A3|go0fhtrDEwMeLiQ0FUnTqiCWjQFtP|Vl29yqwtEf4tFhUeC2kZcQqrYFupxZoiMci0u|Ov|B3|RLSxAlqkgJBSRXsPD62|5M1F|WIFTtwILcC5h|c63rICTuAZDUN2D4bDBE|MM7aIlbOA20ulNmxPda|fzPaOruuuWw8Pq8M2WmNvi5nZkqwulxf8a7T1m|WYjAOFTlGgJucxo0tagxQOSQY2biahhtOPYjWmp3|vUJ4pM22QvxpGaiR5ZLu8fLHmThRGSd7xvZ5b00pPDRjAaWLy8rOSZ7oEYQZ0OOIF0Wy3|mZQHHD2pVW45doOPWAZMar4sDalOaKZ2XTkqdfBGf6u6y6MwOWUJhXPMfONYcRpraDaeaRbUMs|mrNMndPBAUiwXiEmT8Y9zTMQkg3|mNotFNQ83k67G1VrmmsvVfZvoVokPdn24ozUFKWIFv|hoQWbFrkugaYASoJ29cZemxR2KTLnyFFE0a|Ded3LXopoM8FlnpNBSDRwLpXKA1AG1GkvBQs45Bk3cC02IDWLlXNl52IeG597PQXV9l1dYWK2cdQY5w0zsTzMoXaaYBFk4BR1azLC6EFEC4d|kgPm6aBHK7g8bXi|GDH4aXNxiUFsNxKr7QSKnASlbYfhsEKjQIdlrR21BRNwYiGcm|XTudxe0oBRIH2J2arFHCLZQQI9IEODZh4U5UtxzgG6giJAAMLLT8ZHgxzag6ezTMF|tIZnbERA1Pug|BdciDJOX8LGE5Be|RCoQQh1RPn4AjQk2dk9qnbIA6cJ6VmNiLTVkI7YiOEEyz0Ao6gIXr0yIVCnnlCnvBZAewNjHII|JyLqD8xD|2XPkFowlzoxn0I4UQ4ILb7IwkqnIL2CDOs2s3PJsQ7U|QGhsv8BlaLBb98NQWa2DwkTNoP4VQqYO1q7z1GryG8PDJnTm4UdSifAKF5BKi2CfZH9u0rrf|uwO|WR3YUPue5I4MZFN2zZkjsQnDDdkiNJeGUSMo7B7F8AmjbSW|IACk2UCC6xN4FodgBEEnYV8fFKXMXPD48c9zb4Z0HohKa1nqtFZxnCFjBbDOdRFvtLujG74Z4diroFdllrFea8DyIBOIHgn1nRYdNFJc|s4lGREXz4Z0H0FcYEnMvuBt3SftT80GIP8xwvx73KZxkGvEH0WmxoKHpMhQ8j6FDhwr3LF8naELDleEd|5HQ|JhPzyTEiOaARZPTgISNAe0olz5KXB3XDCFpZNaMaf8gBN2ll31cdYPQxcaA53moBoSJcx5cTSKjtS1DGpdsGmA9tsmDZmtMhPBKhIYUBdObuSD6qAmv0Jo9cxrru113TxZORlOz5AknhCAIqG9sQlzCENw58|6CVUsWFlcV8vcQ4N9dC5LX0k471pD1EIPtzaS2o58gpBPMLrjzAihNY39YbTbpwDzHYVCcVvIEg2D|MRJFinhtNFRKVT3lhKw9e74wdqVmmjlsrvhX9zcUBEy|Qkggc2bm5VKQEmc4|YIQBFGCUKtUXe|fYGfR3kOyiu|p6gAw|aIJn1krPy83t77JVOIeTg6HgHqTCQyChZhKKbvqln5SfGhqoLwuZaeuK8B|KZDd35rwCcIeZmWNzE0cFFfiDCemE4cgXA0n|X2dgjy1p|gg|1dbUMN|FHeAg1UBGMgEdN|Rg5odnJGs|2Vh5hDEEqcmdNoYKJXdd2jpLRPy6p69B1cHt|yvZ|XVxmdnj5pCQUvdNdF9HLKppc32fGlpqeXXO2JwO|m8j0zPmzxDrVYXyzIRIa9eabU9|VuEkBKQP96CgrwJPCUbKYGCiPSjok8|3xrcu|WP0Ps24|nYAeBVUAAAAASUVORK5CYII|class|constructor|runtime|getInfo|cActuators|name|categoryName|default|color1|8d0ca8|color2|color3|blocks|DIVLABEL|more|menus|270|pwmPort|aPin|translation_map|tw|cn|kblock|notify|nosupportonlinemode|defaultMessage|Not|support|in|online|VservoWrite|write|wait|need|set|first|readMicroseconds|servoWrite|servo360|nuint16_t|int16_t|writeMicroseconds|motorGo|stopMotor|module|exports','1897485umydiT','2IcaBwN','p\x20b=1m.b,x=1m.x,1n=1m.1n,1W=1m.1W,1o=\x222z:2A/2B;2C,2D+/2E+2F+2G+2H/2I/2J/2K+2L/2M+2N/2O+2P+2Q+2R+2S+2T+2U+2V/2X/2Y+2Z/30+31/32/+33/34+35/36+37/38+39/3a+3b+/3c/3d+3e+3f+3g+3h+3i/3j/3k/3l+3m/3n+3o/3p+3q/3r+3s+2W/3t/3u/3v+3w+3x+3y/3z+3A+V/3B/3C+3D+3E/o+3F/3G+3H+3I+3J/3K/3L/3M+3N/3O+3P/3Q+3R/3S/3T+3U+3V/3W/3X/3Y+3Z/40+41+42+43+44/45+46/47+48/49/n/4a/4b=\x22,1x=1o;4c\x201X{4d(e){y.4e=e}4f(){F{1y:\x224g\x22,4h:1n({1y:\x221Y.4i\x22,4j:\x221Y\x22}),4k:\x22#4l\x22,4m:\x22#1Z\x22,4n:\x22#1Z\x22,1o:1o,1x:1x,4o:[{G:\x221i\x22,z:x.Q,q:\x221z\x201p\x2020\x20w\x201A\x20H\x20I\x20[4]\x20U\x20[i](-9~9)\x22,J:{4:{d:b.l,f:\x226\x22,m:\x221B\x22},i:{d:b.1C,f:21}},D:\x221i\x22,K:{L:y.22}},{G:\x221j\x22,z:x.Q,q:\x221D\x201p\x2020\x20w\x20H\x20I\x20[4]\x22,J:{4:{d:b.l,f:\x226\x22,m:\x221B\x22}},D:\x221j\x22,K:{L:y.23}},\x22---\x22,{G:\x2218\x22,z:x.Q,q:\x221z\x201p\x2024\x20w\x201A\x20H\x20I\x20[4]\x20U\x20[i](-9~9)\x22,J:{4:{d:b.l,f:\x225\x22,m:\x2225\x22},i:{d:b.1C,f:21}},D:\x2218\x22,K:{L:y.1E}},\x22---\x22,{G:\x2219\x22,z:x.Q,q:\x2226\x20w\x20H\x20I\x20[4]\x20(1a\x201q\x201r\x20[s]°)\x2027\x20U\x20[R]°.\x20\x20W:[i](1~9)\x22,J:{s:{d:b.l,f:\x221k\x22,m:\x221l\x22},4:{d:b.l,f:\x222\x22,m:\x221b\x22},R:{d:b.28,f:0},i:{d:b.29,f:9}},D:\x2219\x22,K:{L:y.1F}},{G:\x221G\x22,z:x.Q,q:\x222a\x202b\x20E\x20w\x20H\x20I\x20[4]\x20U\x201H\x22,J:{4:{d:b.l,f:\x222\x22,m:\x221b\x22}},D:\x22X\x22,K:{L:y.1I}},{G:\x221J\x22,z:x.Q,q:\x221D\x20E\x20w\x20H\x20I\x20[4]\x22,J:{4:{d:b.l,f:\x222\x22,m:\x221b\x22}},D:
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

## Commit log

2022-10-09 add mx1505 Hbridge motor driver arduino lib
2022-10-09 add stop motor fuction
2022-10-14 update continuius servo Port
2022-10-21 use 2 pwm pins for motorH
2022-10-29 update Arduino Firmata and johnny-five node lib
2022-11-30 add onboard sensor marks
2022-12-16 update color sensor code
2022-12-19 update color sensor blocks
2022-12-19 add onboard imu
2022-12-28 update imu blocks
2022-12-29 update imu functions
2023-01-18 add more imu blocks
2023-01-25 imu blocks debug and add a resetYaw block
    [index.js]
2023-01-26 add imu online function
2023-01-27 add a core Temp. block and on-line reset Yaw function
    [index.js]
2023-01-28 簡化mpu codes
2023-01-29 replace tilt SW by IMU
2023-02-22 ultrasonic unit from cm to mm and more examples
2023-03-05 use slow_decay mode for on-line motorH
2023-03-17 增加一些翻譯
2023-03-19 更改翻譯
2023-05-09 code 排列整齊
2023-05-11 debug aaReal(加速度)
2023-05-11 debug float 運算+小數點, & local變數積木
2023-05-12 digital_read積木塊增加選pin功能
2023-05-13 修改變數宣告積木塊
2023-05-16 ISR pin增加 pinMode(pin, INPUT)
2023-05-19 微調加減速
2023-05-20 修正變數積木塊不能=字串 issue
2023-05-24 修正 yaw歸零 範圍超過+-180的issue
2023-05-27 add 1D kalma filter
2023-05-28 增加kalman積木塊中文翻譯
2023-06-02 add off-line timer fuction & 修改翻譯
2023-06-02 add more off-line servo fuctions
2023-06-03 修改翻譯
2023-06-13 簡化mpufailed( ) 代碼
2023-07-13 增加A6, A7並重整RJport
2023-07-13 改icon, 增加範例, 改android 遙控app
2023-07-17 回復原程式
2023-07-17 更改引用Firmata方法
2023-07-17 讓firmata 支援A6, A7
2023-07-18 修改Firmata 讓Analog pin 也能跑servo
2023-07-18 改小馬達接口
2023-07-18 更改dPort可用接口
2023-07-19 debug: on-line時 1st digitalread() 值錯誤issue
2023-07-20 debug online yaw reading
2023-07-25 debug: online yaw range
2023-07-25 debug: online ping read issue
    [cBrainFirmata.js, index.js]
2023-07-25 update servo codes
2023-07-25 找回4年前正確的online codes
2023-07-27 增加地磁偏角校正
2023-07-27 i2c read16 檢查正負號
2023-07-28 add on-line timer fuction
2023-07-30 加密, 整理, update說明
2023-07-30 整理arduino lib
2023-07-30 原檔加密後無法使用, 改混淆
2023-07-31 加密後有bug, 改混淆
2023-08-02 縮短online interval time
2023-08-02 縮短online intervaltime to 1ms
2025-07-19 docs(README): 更新 funXbot v1 和 funXblock 相关说明
    - 添加 funXbot v1 硬件和 funXblock 软件的详细介绍
    - 新增 DIY 材料清单和所需工具说明
    - 添加 funXbot v1 组装方法的详细步骤
    - 更新 funXblock 安装方法的说明
    - 添加项目授权说明
    - 优化 README 文档的结构和格式
2025-07-19 增加硬件製作說明及相關檔案
2025-07-19 docs(README): 更新硬件組裝步驟图片
2025-07-20 docs(README): 更新 funXbot v1 製作方法
    - 修改目錄結構，重新組織內容
    - 添加詳細的製作步驟说明，包括主機、電池盒、感應器、顯示設備和馬達的接線方法
    - 插入多張示意圖，以便使用者參考
    - 新增了 3D 打印外殼的建議
    [9g_servo_fitting_doublepully.STL, HC-SR04 v2.stl, SG90_-_Micro_Servo_9g_-_Tower_Pro_v2_LEGO.stl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]
2025-07-20 Update README.md, 增加工具項
2025-07-20 Update README.md 修詞
2025-07-20 docs(README): 添加 funXbot v1 套件玩法示例
2025-07-20 修改README.md內demo圖示
2025-07-20 README.md 修正RJ11 線材說明
2025-07-21 docs(README): 更新 funXbot v1 文档
    - 修改项目概述,增加 funXtcp 模块说明
    - 更新硬件设备列表,增加 PCF8574T IO 扩展模块
    - 修正 RJ11 水晶头的描述
    - 补充制作其他设备的详细说明,特别是循线传感器
    - 调整软件使用说明的位置,移到更合适的位置
    - 删除重复的软件使用说明部分
    - 更新图片路径,删除不再使用的图片
2025-07-21 README.md修辭
2025-07-21 README.md排版
2025-07-21 README.md修飾排版
2025-07-21 docs(README): 更新 logo 图片路径
    - 将 logo 图片路径从根目录移动到 doc 目录
    - 删除根目录下的 funxedu-logo4-black.png 和 funxedu-logo4-white.png 文件
2025-07-24 Update README.md 檔案下載連結
2025-07-24 Update README.md 修辭
